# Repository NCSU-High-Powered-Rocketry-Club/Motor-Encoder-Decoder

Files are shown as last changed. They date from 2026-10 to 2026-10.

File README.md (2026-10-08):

# Motor Encoder Decoder
This project contains the KiCad files for HPRC's Motor Encoder Decoder board. This PCB was designed for the club's rover payload, which will be flown in the 2027 IREC competition.

## Description
The Motor Encoder Decoder is intended to be used with a [Motoron M2T256 Dual I2C Motor Controller](https://www.pololu.com/product/5065) and powers two 12V DC motors using JST connectors. These connectors will connect to [Pololu rotary encoders](https://www.pololu.com/product/5661) that will be mounted on the gear motors for the rover's wheels. Encoder position is received through these connectors in the form of quadrature square waves and counted with the LS7866C quadrature counter. This data is retrieved off the board using the same i2c bus that controls the motors.



## Component Overview
The [LS7866C](https://lsicsi.com/wp-content/uploads/2025/05/LS7866C.pdf) is the primary component of this board, allowing the quadrature encoder data to be connected directly and counted, up to 32 bits. The primary motivation for this was to free up GPIO's and computation time from the Raspberry Pi, as well as being more robust instead of relying on the Pi's OS catching every clock edge.

A board-mount Wago is used for easy connection of the main power, and reliability for the high-current connection. The board was designed with 1.8A peak current per motor in mind, and the Wago is more than capable of handling this. We are supplying 12V to the Wago to power the motors on the rover.

The board is powered using 3.3V to power the LS7866C, and must use 3.3V logic-level I2C.

## PCBWay
A special thank you to our sponsor, [PCBWay](https://www.pcbway.com/), for supporting the manufacturing of this custom PCB! As a competitive high-powered rocketry team, reliable electronics are essential to the success of our projects. PCBWay's high-quality PCB manufacturing services have helped us turn our designs into functional hardware, allowing us to develop and test custom electronics for our rockets and payloads. Their support, attention to detail, and excellent communication throughout the manufacturing process have been greatly appreciated. We are grateful for their contribution to our team's success and highly recommend checking out their services for your next electronics project!



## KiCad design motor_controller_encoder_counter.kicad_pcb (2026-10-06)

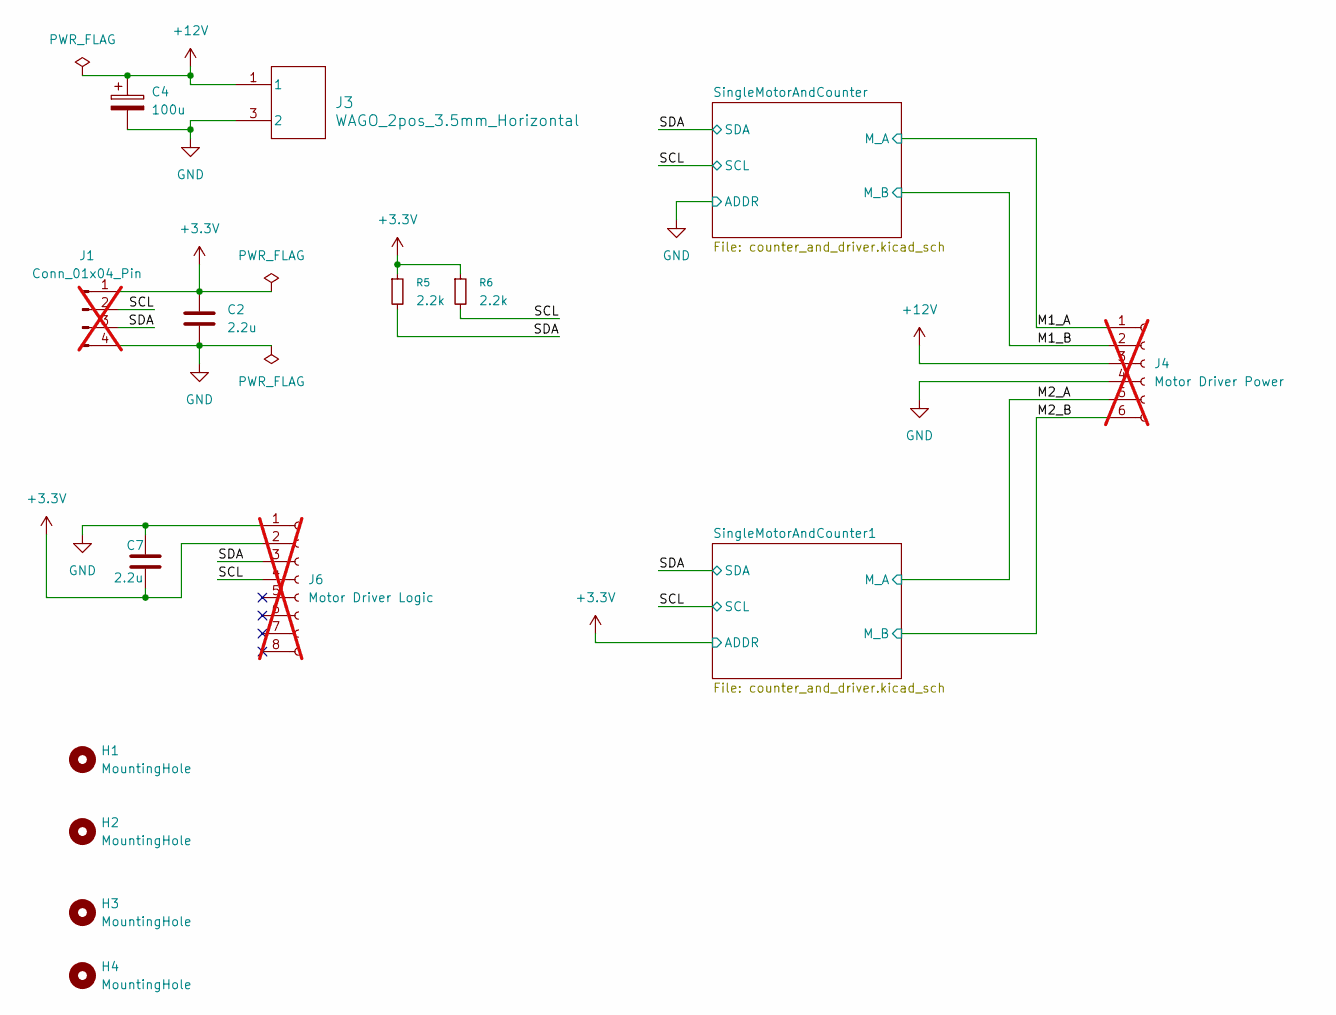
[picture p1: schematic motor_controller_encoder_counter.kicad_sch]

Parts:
C2, C7: 2.2u; C_0402_1005Metric; Manufacturer PN GRM155R61C225KE44D
C4: 100u; CP_Elec_5x5.8; Manufacturer PN APXG160ARA101ME61G
H1, H2, H3, H4: MountingHole; MountingHole_2.2mm_M2
J1: Conn_01x04_Pin; PinHeader_1x04_P2.54mm_Vertical; not fitted
J3: WAGO_2pos_3.5mm_Horizontal; Manufacturer PN 2601-1102
J4: Motor Driver Power; PinSocket_1x06_P2.54mm_Vertical; not fitted
J6: Motor Driver Logic; PinSocket_1x08_P2.54mm_Vertical; not fitted
R5, R6: 2.2k; R_0402_1005Metric; Manufacturer PN RC0402FR-072k2L

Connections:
+3.3V: C2.2, C7.1, J1.1, J6.2, R5.1, R6.1; also elsewhere on the board
+12V: C4.1, J3.1, J3.2 (1_2), J4.3
/M1_A: J4.1; also elsewhere on the board
/M1_B: J4.2; also elsewhere on the board
/M2_A: J4.5; also elsewhere on the board
/M2_B: J4.6; also elsewhere on the board
/SCL: J1.2, J6.4, R6.2; also elsewhere on the board
/SDA: J1.3, J6.3, R5.2; also elsewhere on the board
GND: C2.1, C4.2, C7.2, J1.4, J3.3 (2), J3.4 (2_2), J4.4, J6.1; also elsewhere on the board

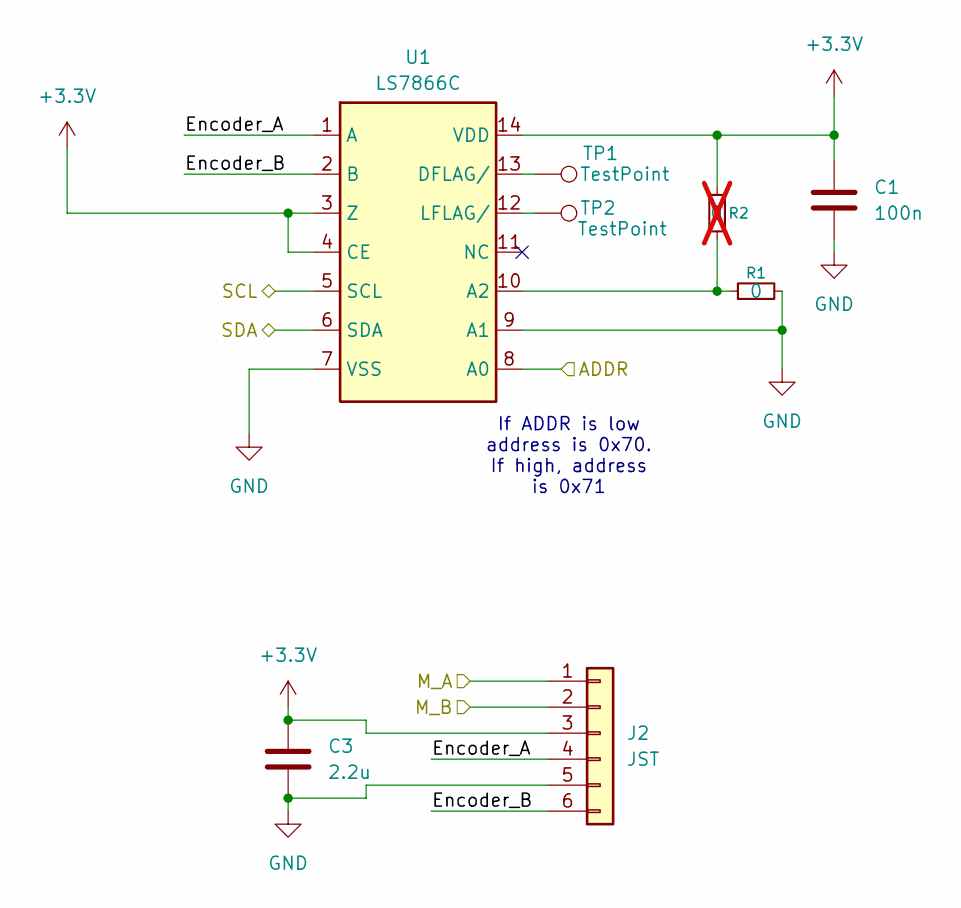
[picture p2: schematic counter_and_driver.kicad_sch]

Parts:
C1: 100n; C_0402_1005Metric; Manufacturer PN GCM155R71H104KE02D
C3: 2.2u; C_0402_1005Metric; Manufacturer PN GRM155R61C225KE44D
J2: JST; JST_PH_S6B-PH-K_1x06_P2.00mm_Horizontal; Manufacturer PN S6B-PH-K-S
R1: 0; R_0402_1005Metric; Manufacturer PN RC0402FR-070RL
R2: 0; R_0402_1005Metric; not fitted
TP1, TP2: TestPoint; TestPoint_Pad_1.0x1.0mm
U1: LS7866C; TSSOP-14_4.4x5mm_P0.65mm; Manufacturer PN LS7866C-TS

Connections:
+3.3V: C1.2, C3.1, J2.3, R2.2, U1.3 (Z), U1.4 (CE), U1.14 (VDD); also elsewhere on the board
/M1_A: J2.1; also elsewhere on the board
/M1_B: J2.2; also elsewhere on the board
/SCL: U1.5 (SCL); also elsewhere on the board
/SDA: U1.6 (SDA); also elsewhere on the board
/SingleMotorAndCounter/Encoder_A: J2.4, U1.1 (A)
/SingleMotorAndCounter/Encoder_B: J2.6, U1.2 (B)
GND: C1.1, C3.2, J2.5, R1.2, U1.7 (VSS), U1.8 (A0), U1.9 (A1); also elsewhere on the board
unnamed: R1.1, R2.1, U1.10 (A2)
unnamed: TP1.1 (1_1), U1.13 (DFLAG/)
unnamed: TP2.1 (1_1), U1.12 (LFLAG/)

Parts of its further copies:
C5: 100n; C_0402_1005Metric; Manufacturer PN GCM155R71H104KE02D
C6: 2.2u; C_0402_1005Metric; Manufacturer PN GRM155R61C225KE44D
J8: JST; JST_PH_S6B-PH-K_1x06_P2.00mm_Horizontal; Manufacturer PN S6B-PH-K-S
R3: 0; R_0402_1005Metric; not fitted
R4: 0; R_0402_1005Metric; Manufacturer PN RC0402FR-070RL
TP3, TP4: TestPoint; TestPoint_Pad_1.0x1.0mm
U2: LS7866C; TSSOP-14_4.4x5mm_P0.65mm; Manufacturer PN LS7866C-TS

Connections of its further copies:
+3.3V: C5.2, C6.1, J8.3, R3.2, U2.3 (Z), U2.4 (CE), U2.8 (A0), U2.14 (VDD); also elsewhere on the board
/M2_A: J8.1; also elsewhere on the board
/M2_B: J8.2; also elsewhere on the board
/SCL: U2.5 (SCL); also elsewhere on the board
/SDA: U2.6 (SDA); also elsewhere on the board
/SingleMotorAndCounter1/Encoder_A: J8.4, U2.1 (A)
/SingleMotorAndCounter1/Encoder_B: J8.6, U2.2 (B)
GND: C5.1, C6.2, J8.5, R4.2, U2.7 (VSS), U2.9 (A1); also elsewhere on the board
unnamed: R3.1, R4.1, U2.10 (A2)
unnamed: TP3.1 (1_1), U2.13 (DFLAG/)
unnamed: TP4.1 (1_1), U2.12 (LFLAG/)

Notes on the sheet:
If ADDR is low address is 0x70. If high, address is 0x71

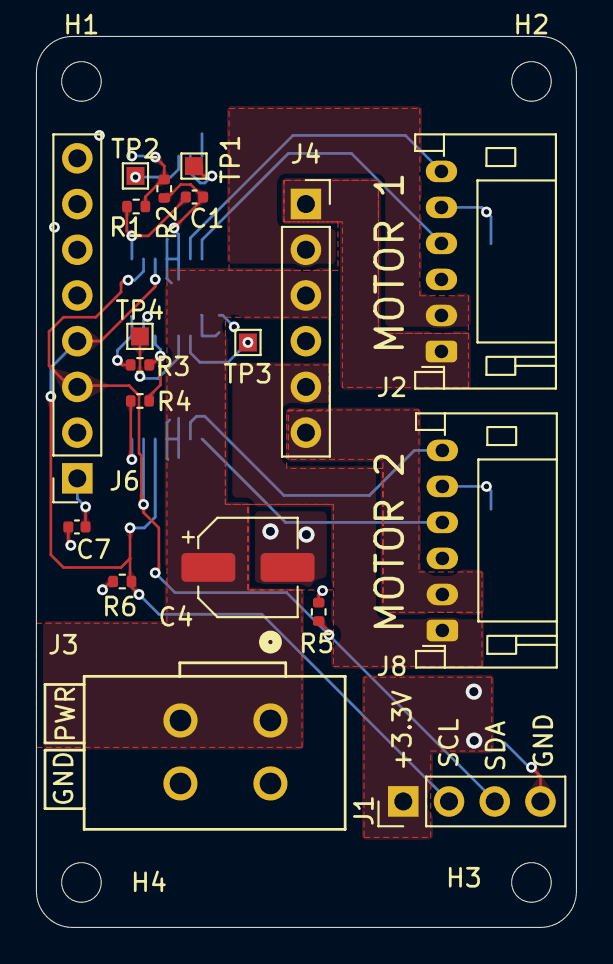
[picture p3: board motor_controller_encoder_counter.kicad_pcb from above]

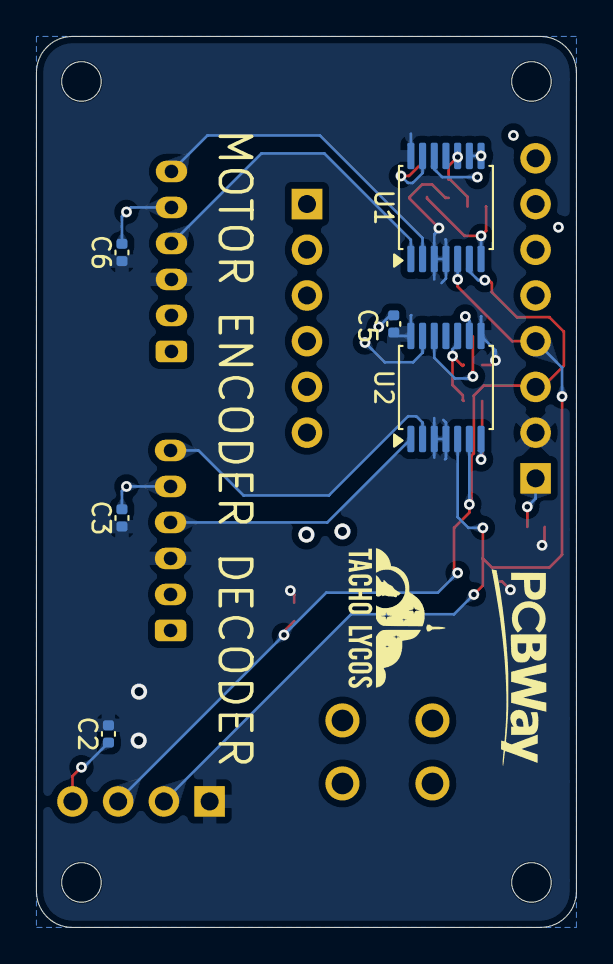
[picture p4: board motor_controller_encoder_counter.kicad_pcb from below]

Board: 4 copper layers, 30.0 x 49.5 mm, 29 parts (6 on the bottom side), 19 nets.

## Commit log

2026-09-12 initial pcb schematic and design
    [counter_and_driver.kicad_sch, motor_controller_encoder_counter.kicad_pcb, motor_controller_encoder_counter.kicad_sch]
2026-09-29 ready for review
    [counter_and_driver.kicad_sch, motor_controller_encoder_counter.kicad_pcb, motor_controller_encoder_counter.kicad_sch]
2026-10-04 added teardrops
    [motor_controller_encoder_counter.kicad_pcb]
2026-10-06 ready to review
    [motor_controller_encoder_counter.kicad_pcb]
2026-10-08 Update README with project and PCBWay details
    Expanded project description and added component overview.
